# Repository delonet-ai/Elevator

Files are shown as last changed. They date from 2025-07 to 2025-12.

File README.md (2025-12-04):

Project migrateg on ESP32, now available here: https://github.com/delonet-ai/Elevator-ESP32 **WIREELESS REMOTE!!**

Проект переехал на ESP32, доступен вот тут: https://github.com/delonet-ai/Elevator-ESP32

**English version below**
# 🚀 Макет лифта на Arduino
BOM и STL будут внизу.
Фотки в папке pics

Этот проект реализует управление шаговым двигателем с помощью Arduino Nano для перемещения лифта между тремя этажами. Прошивка поддерживает автоматическую калибровку, ручное управление и вызовы на этажи. 
Roadmap:
- Хранение калибровки и текущей позиции в EEPROM
- плавный разгон-торможение
- вывод на дисплей 128х32 точки информации о движении и этаже
- Переделка пульта с 14 жил на 4 через еще одну Arduino Nano
- Перевод на питание через 4S 18650 и BMS
- Экстренный режим (если нажат концевик)
- Перевод в режим рекалибровки и сброс всех данных EEPROM
## ⚙️ Возможности

* Поддержка 3 этажей
* Калибровка верхней и нижней границ
* Режим ручного управления (вверх/вниз)
* Вызов на этажи кнопками
* Световая индикация кнопок
* Отображение статуса в Serial Monitor
* Плавное ускорение и торможение в авто-режиме
* Регулируемая скорость с помощью потенциометра

## 🔌 Подключение компонентов

| Компонент | Пин Arduino | Описание |
| --- | --- | --- |
| Кнопка "Вверх" | D10 | Режим INPUT\_PULLUP |
| Кнопка "Вниз" | D11 | Режим INPUT\_PULLUP |
| Кнопка "Этаж 1" | D7 | Режим INPUT\_PULLUP |
| Кнопка "Этаж 2" | D8 | Режим INPUT\_PULLUP |
| Кнопка "Этаж 3" | D9 | Режим INPUT\_PULLUP |
| Подсветка "Вверх" | D5 | LOW = включено |
| Подсветка "Вниз" | D6 | LOW = включено |
| Подсветка Этаж 1 | D2 | LOW = включено |
| Подсветка Этаж 2 | D3 | LOW = включено |
| Подсветка Этаж 3 | D4 | LOW = включено |
| Шаговый двигатель STEP | D13 | Сигнал шагов |
| Шаговый двигатель DIR  | A3 | Направление вращения |
| Концевик (верхний) | A1 | Режим INPUT\_PULLUP |
| Потенциометр | A2 | Задаёт скорость движения |

Если вы не поняли про водсветку - кнопки у меня с резистром на подсветке, поэтому подключены к +5, а пины дают землю при включении.

## 🛠 Установка
Если вы здесь - вы знаете как загрузить .ino в вашу ардуино

## 📏 Калибровка

1. Кнопками "Вверх" и "Вниз" подведите кабину к верхней точке.
2. Нажмите концевик → верхняя граница будет установлена.
3. Кнопкой "Вниз" опустите кабину до низа.
4. Коротким нажатием кнопки "Этаж 1" установите нижнюю границу.
5. После этого доступен авто-режим: кнопки этажей начинают работать.

## 🚦 Управление

* Нажатие кнопки этажа вызывает лифт к нужному уровню.
* Подсветка кнопки загорается на время движения.
* При движении вверх/вниз вручную используется минимальная скорость.
* В авто-режиме скорость — в зависимости от положения потенциометра (1–15×).

## ⚡ Конфигурация

```cpp
const unsigned int STEP_DELAY = 1000;  // Минимальная задержка (медленное движение)
```

Скорость регулируется через потенциометр на A2 (map в диапазон от 1 до 15).

## 🧪 Отладка

Открывайте Serial Monitor (9600 бод), чтобы видеть:

* Текущую позицию
* Режим работы (MANUAL / AUTO)
* Целевую позицию

---

!!! BOM:
- 4 трубы 25мм - 1 метр (или любая высота)
- 3д принтер и PLA пластик (1-1,5 кг)
- Название	Кол-во	Примечание
- Arduino Nano	https://sl.aliexpress.ru/p?key=4FCD3xc
- Плата для разводки https://sl.aliexpress.ru/p?key=JFCD3Y3
- Шаговый мотор NEMA17
- Плата для драйвера https://sl.aliexpress.ru/p?key=DnCD3wO
- Драйвер A4988	1	Обязательно радиатор и термопрокладка https://sl.aliexpress.ru/p?key=tFCD3EM
- БП 12 В (2–5 А)	или BMS + 4s 16650 + dc-dc на 12В
- Потенциометр 10 кОм	1	
- OLED-дисплей SSD1306 (0.91")	1	I2C, 128×32, SSD1306
- Кнопки с подстветкой https://sl.aliexpress.ru/p?key=mFCD3h2 

!!! STL + Fusion 360 в папке /CAD и по ссылке
https://www.printables.com/model/1353500-elevator-lift-arduino
https://www.thingiverse.com/thing:7089874

Если используете этот проект — ⭐ на GitHub приветствуется!

*Удачных проектов!*

**English version**

🚀 Arduino Elevator Model

BOM and STL are at the bottom.
Photos are in the pics folder.

This project implements a stepper-motor–driven elevator controller based on an Arduino Nano, supporting movement between three floors.
The firmware includes automatic calibration, manual control, and floor call buttons.

Roadmap:

Store calibration and current position in EEPROM

Smooth acceleration/braking

Display movement status and current floor on a 128×32 OLED

Rework the remote controller from 14 wires down to 4 using an additional Arduino Nano

Power the entire system using a 4S 18650 pack and BMS

Emergency mode (triggered by the upper limit switch)

Recalibration mode and EEPROM wipe

⚙️ Features

3-floor support

Calibration of top and bottom limits

Manual control mode (up/down)

Floor-call buttons

Button illumination

Status output via Serial Monitor

Smooth acceleration and braking in auto mode

Adjustable speed via potentiometer

🔌 Component Connections
Component	Arduino Pin	Description
“Up” button	D10	INPUT_PULLUP mode
“Down” button	D11	INPUT_PULLUP mode
Floor 1 button	D7	INPUT_PULLUP mode
Floor 2 button	D8	INPUT_PULLUP mode
Floor 3 button	D9	INPUT_PULLUP mode
Up indicator LED	D5	LOW = on
Down indicator LED	D6	LOW = on
Floor 1 LED	D2	LOW = on
Floor 2 LED	D3	LOW = on
Floor 3 LED	D4	LOW = on
Stepper STEP	D13	Step signal
Stepper DIR	A3	Direction signal
Limit switch (top)	A1	INPUT_PULLUP mode
Potentiometer	A2	Controls movement speed

If you're confused about the LED wiring — the buttons I use have built-in resistors for LEDs.
They are connected to +5V, and Arduino pins provide ground when turning illumination on.

🛠 Installation

If you’re here, you already know how to upload a .ino to your Arduino.

📏 Calibration

Use the “Up” / “Down” buttons to move the cabin to the top position.

Press the limit switch → the upper boundary is saved.

Use the “Down” button to lower the cabin to the bottom.

Short-press the “Floor 1” button to save the bottom boundary.

After this, auto mode becomes available: floor buttons start working.

🚦 Operation

Pressing a floor button moves the elevator to that floor.

The button’s LED lights up during movement.

Manual up/down movement always uses minimum speed.

In auto mode, speed depends on the potentiometer position (1–15×).

⚡ Configuration
const unsigned int STEP_DELAY = 1000;  // Minimum delay (slow movement)

Speed is controlled by the potentiometer on A2 (mapped from 1 to 15).

🧪 Debugging

Open Serial Monitor (9600 baud) to see:

Current position

Mode (MANUAL / AUTO)

Target position

!!! BOM:

25mm pipes ×4 — 1 meter (or any height)

3D printer + PLA filament (1–1.5 kg)

Name | Qty | Notes

Arduino Nano — https://sl.aliexpress.ru/p?key=4FCD3xc

Breakout board — https://sl.aliexpress.ru/p?key=JFCD3Y3

Stepper motor NEMA17

Driver carrier board — https://sl.aliexpress.ru/p?key=DnCD3wO

Driver A4988 ×1 — requires heatsink + thermal pad https://sl.aliexpress.ru/p?key=tFCD3EM

PSU 12 V (2–5 A) or BMS + 4s 16650 + DC-DC to 12 V

Potentiometer 10 kΩ ×1

OLED display SSD1306 (0.91") ×1 — I2C, 128×32, SSD1306

Lighted push buttons — https://sl.aliexpress.ru/p?key=mFCD3h2

!!! STL + Fusion 360 in /CAD and here:
https://www.printables.com/model/1353500-elevator-lift-arduino

https://www.thingiverse.com/thing:7089874

If you use this project — ⭐ on GitHub is appreciated!

Happy building!

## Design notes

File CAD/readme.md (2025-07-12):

Это мой 3д проект, его можно посмотреть вот тут или файлы в этой папке. Тут, скорее всего, они новее.

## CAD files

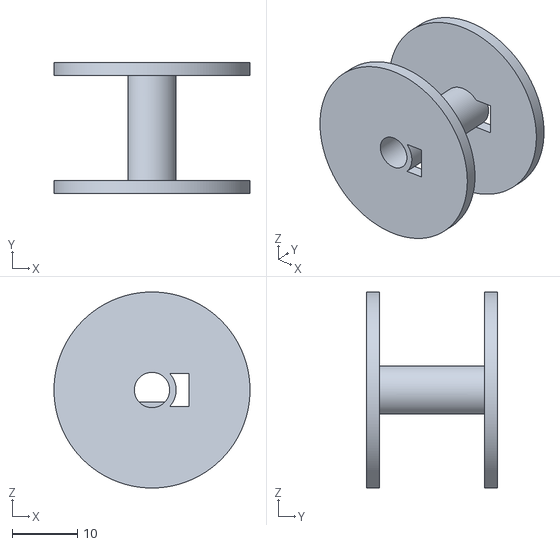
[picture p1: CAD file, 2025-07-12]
CAD/Pulley.stl
30.0 x 20.0 x 30.0

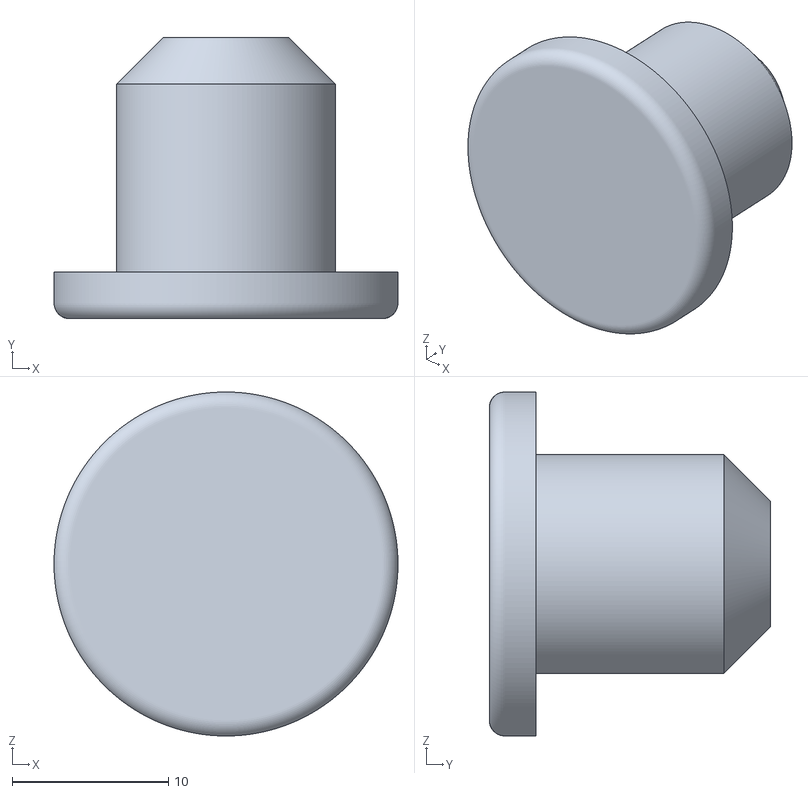
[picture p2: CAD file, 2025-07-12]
CAD/Pin.stl
22.0 x 18.0 x 22.0

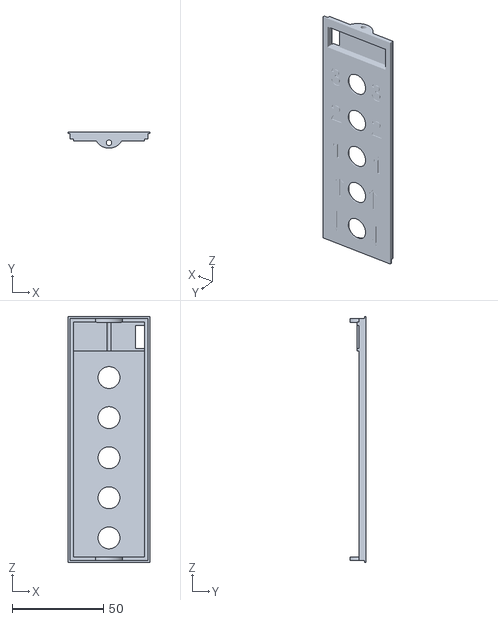
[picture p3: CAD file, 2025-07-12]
CAD/ControlCover.stl
45.0 x 8.99 x 135.0

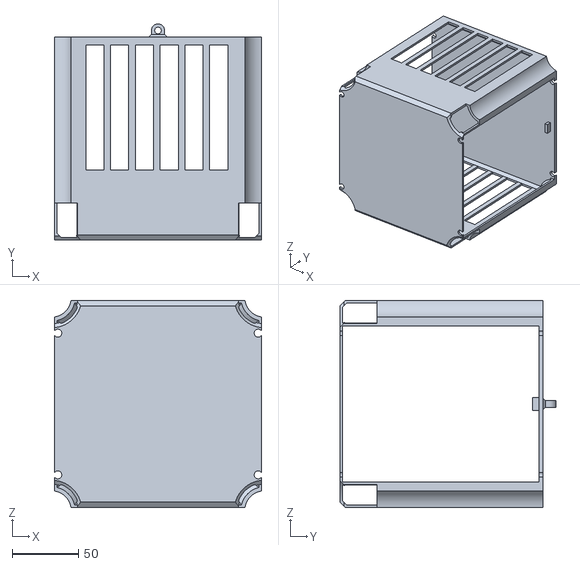
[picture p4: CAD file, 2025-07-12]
CAD/Cabin2.stl
156.0 x 163.0 x 156.0

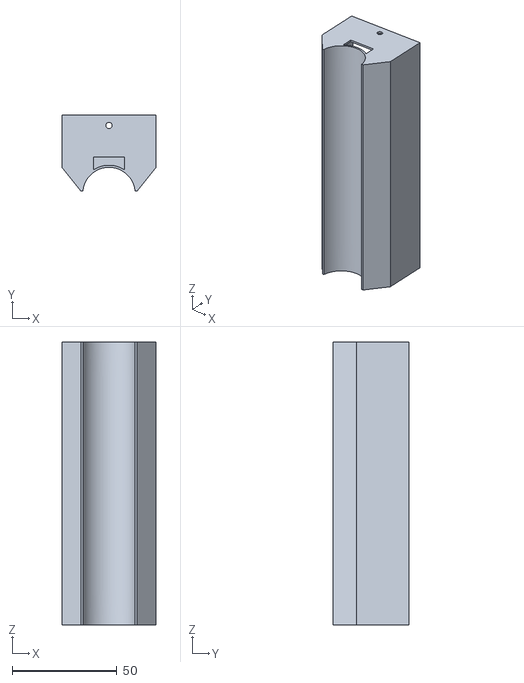
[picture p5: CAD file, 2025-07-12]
CAD/ControlBox.stl
45.0 x 36.3 x 135.0

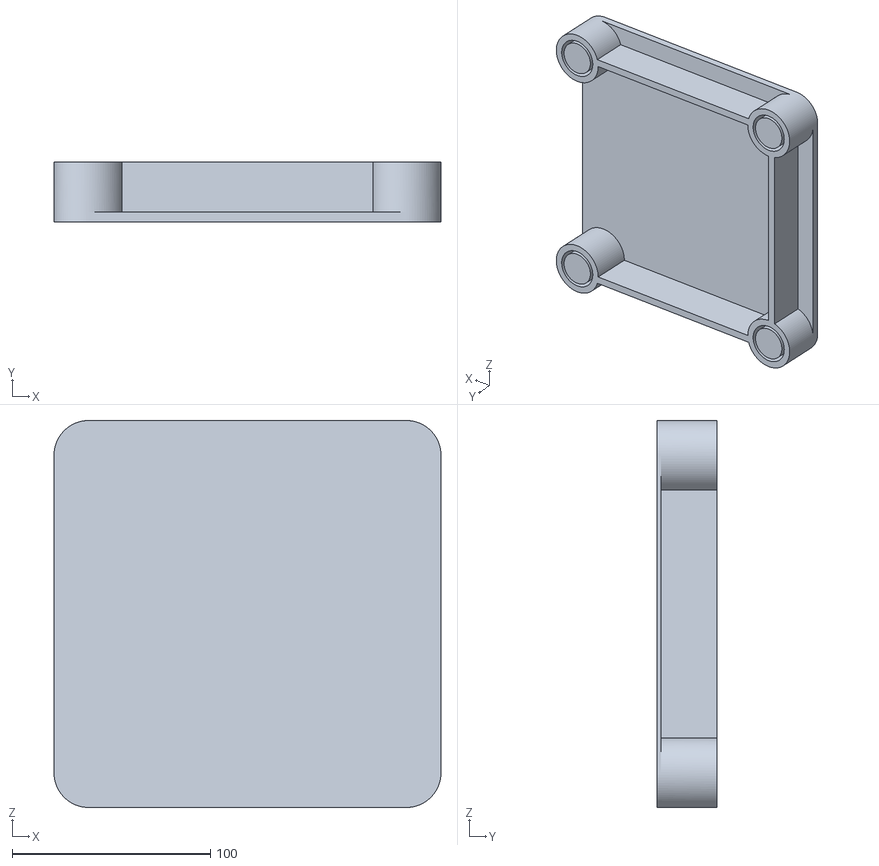
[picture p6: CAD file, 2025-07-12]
CAD/Bottom.stl
195.0 x 30.0 x 195.0

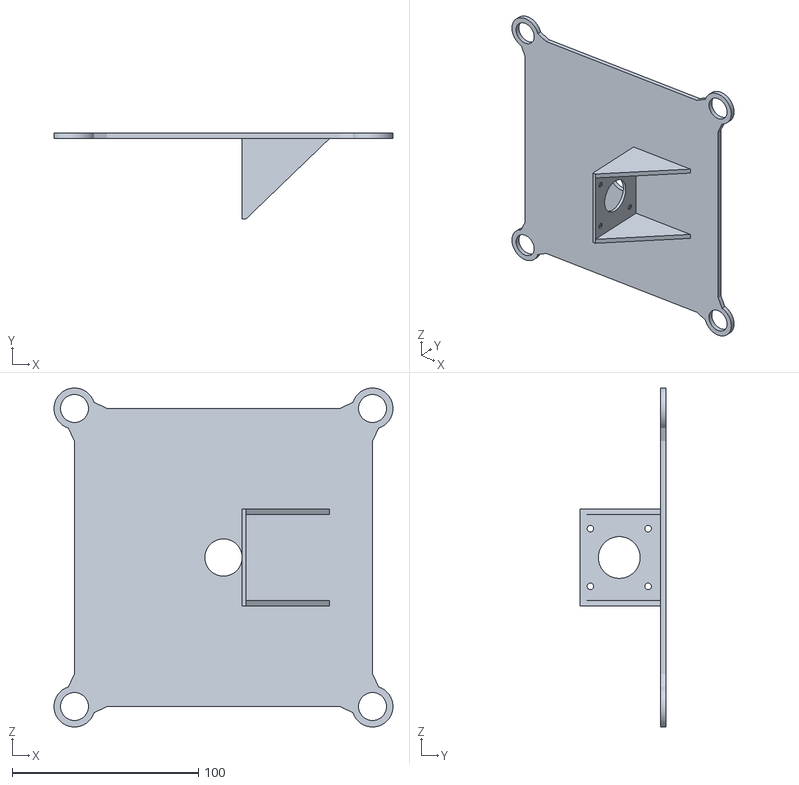
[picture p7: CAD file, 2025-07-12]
CAD/DriveBoard.stl
182.0 x 46.3 x 182.0

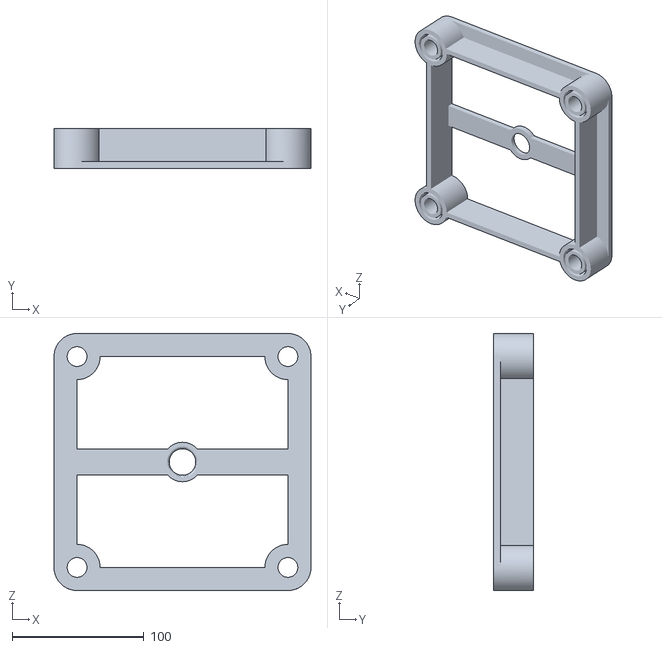
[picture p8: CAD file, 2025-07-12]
CAD/Top.stl
195.0 x 30.0 x 195.0

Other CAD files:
CAD/Elevator v19.f3d

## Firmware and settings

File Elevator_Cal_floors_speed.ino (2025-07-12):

// Elevator Sketch with Floor Call Logic
// Calibration (upper and lower limits) then floor calls for 3 floors

#include <Arduino.h>

// Pin Definitions
#define BTN_UP        10    // Manual UP (INPUT_PULLUP)
#define BTN_DOWN      11    // Manual DOWN
#define BTN_FLOOR1    7     // Floor1: first sets lower limit, then floor call
#define BTN_FLOOR2    8     // Floor2 call
#define BTN_FLOOR3    9     // Floor3 call
#define PIN_STEP      13    // Stepper STEP pin
#define PIN_DIR       A3    // Stepper DIR pin
#define LIMIT_TOP     A1    // Top limit switch (INPUT_PULLUP)
#define PIN_POT       A2    // Potentiometer for speed factor (analog input)

// LED Pins (active-low: LOW = ON)
#define LED_UP        5
#define LED_DOWN      6
#define LED_FLOOR1    2
#define LED_FLOOR2    3
#define LED_FLOOR3    4

// Timing constants
const unsigned int STEP_DELAY       = 100;  // base delay in microseconds
const unsigned long BLINK_INTERVAL  = 200;   // ms for floor LEDs fast blink

// State tracking
long positionCounter    = 0;
bool upperLimitLocked   = false;
bool lowerLimitSet      = false;
long lowerLimit         = 0;       // threshold for DOWN movement
long floor3Limit        = 0;       // 2% from lowerLimit

// Floor call logic
enum MoveMode { MANUAL, AUTO };
MoveMode mode = MANUAL;
long targetPosition = -1;

// Edge tracking
bool lastFloor1State    = HIGH;
bool lastFloor2State    = HIGH;
bool lastFloor3State    = HIGH;
bool lastLimitState     = HIGH;

// LED blink for floor buttons
unsigned long blinkLastTime = 0;
bool blinkState            = false;

// Speed factor variable
unsigned int stepDelay = STEP_DELAY;

void setup() {
  Serial.begin(9600);
  while (!Serial);
  Serial.println("[Setup] Elevator ready");

  // Configure inputs
  pinMode(BTN_UP, INPUT_PULLUP);
  pinMode(BTN_DOWN, INPUT_PULLUP);
  pinMode(BTN_FLOOR1, INPUT_PULLUP);
  pinMode(BTN_FLOOR2, INPUT_PULLUP);
  pinMode(BTN_FLOOR3, INPUT_PULLUP);
  pinMode(LIMIT_TOP, INPUT_PULLUP);
  pinMode(PIN_POT, INPUT);

  // Configure motor outputs
  pinMode(PIN_STEP, OUTPUT);
  pinMode(PIN_DIR, OUTPUT);

  // Configure LEDs
  pinMode(LED_UP, OUTPUT); digitalWrite(LED_UP, HIGH);
  pinMode(LED_DOWN, OUTPUT); digitalWrite(LED_DOWN, HIGH);
  pinMode(LED_FLOOR1, OUTPUT); digitalWrite(LED_FLOOR1, HIGH);
  pinMode(LED_FLOOR2, OUTPUT); digitalWrite(LED_FLOOR2, HIGH);
  pinMode(LED_FLOOR3, OUTPUT); digitalWrite(LED_FLOOR3, HIGH);
}

void loop() {
  unsigned long now = millis();

  // Read speed factor from potentiometer
  int potVal = analogRead(PIN_POT);             // 0..1023
  unsigned int factor = map(potVal, 0, 1023, 1, 15);
  stepDelay = STEP_DELAY * factor;

  // Read inputs
  bool upHeld     = (digitalRead(BTN_UP) == LOW);
  bool downHeld   = (digitalRead(BTN_DOWN) == LOW);
  bool f1         = (digitalRead(BTN_FLOOR1) == LOW);
  bool f2         = (digitalRead(BTN_FLOOR2) == LOW);
  bool f3         = (digitalRead(BTN_FLOOR3) == LOW);
  bool limitTop   = (digitalRead(LIMIT_TOP) == LOW);

  // Handle top limit (edge)
  if (limitTop && lastLimitState == HIGH) {
    positionCounter = 0;
    upperLimitLocked = true;
    Serial.println("[Calib] Top set, Counter=0");
  }
  lastLimitState = limitTop;

  // Lower limit setup: only if upper calibrated but lower not set
  if (upperLimitLocked && !lowerLimitSet && f1 && lastFloor1State == HIGH) {
    lowerLimitSet = true;
    lowerLimit = positionCounter;
    floor3Limit = (long)(lowerLimit * 0.02);  // compute third floor offset
    Serial.print("[Calib] Lower set="); Serial.println(lowerLimit);
    Serial.print("[Calib] Floor3 limit="); Serial.println(floor3Limit);
  }

  // Floor calls: only after both limits set, f1 now acts as call
  if (upperLimitLocked && lowerLimitSet && mode == MANUAL) {
    if (f1 && lastFloor1State == HIGH) {
      targetPosition = lowerLimit;
      mode = AUTO;
      Serial.print("[Call] Floor1 target="); Serial.println(targetPosition);
    } else if (f2 && lastFloor2State == HIGH) {
      targetPosition = lowerLimit / 2;
      mode = AUTO;
      Serial.print("[Call] Floor2 target="); Serial.println(targetPosition);
    } else if (f3 && lastFloor3State == HIGH) {
      targetPosition = (long)(lowerLimit * 0.02);
      mode = AUTO;
      Serial.print("[Call] Floor3 target="); Serial.println(targetPosition);
    }
  }
  lastFloor1State = f1;
  lastFloor2State = f2;
  lastFloor3State = f3;

  // Update blink state for floor LEDs
  if (now - blinkLastTime >= BLINK_INTERVAL) {
    blinkLastTime = now;
    blinkState = !blinkState;
  }

  // Floor LED logic
  if (!upperLimitLocked) {
    // Before top limit set: blink floors 1-3
    digitalWrite(LED_FLOOR1, blinkState ? LOW : HIGH);
    digitalWrite(LED_FLOOR2, blinkState ? LOW : HIGH);
    digitalWrite(LED_FLOOR3, blinkState ? LOW : HIGH);
  } else if (upperLimitLocked && !lowerLimitSet) {
    // After top limit only: Floor1 steady on
    digitalWrite(LED_FLOOR1, LOW);
    digitalWrite(LED_FLOOR2, HIGH);
    digitalWrite(LED_FLOOR3, HIGH);
  } else {
    // After both limits: default floors off
    digitalWrite(LED_FLOOR1, HIGH);
    digitalWrite(LED_FLOOR2, HIGH);
    digitalWrite(LED_FLOOR3, HIGH);
  }

  // Floor call indication during AUTO mode
  if (mode == AUTO) {
    // Light target floor LED until arrival
    if (targetPosition == lowerLimit) {
      digitalWrite(LED_FLOOR1, LOW);
    } else if (targetPosition == lowerLimit/2) {
      digitalWrite(LED_FLOOR2, LOW);
    } else if (targetPosition == (long)(lowerLimit*0.02)) {
      digitalWrite(LED_FLOOR3, LOW);
    }
  }

  // UP/DOWN LED logic: on when movement allowed (manual or auto)
  bool canUp;
  if (mode == MANUAL && lowerLimitSet) canUp = (positionCounter > floor3Limit);
  else canUp = (!upperLimitLocked || positionCounter > 0);
  bool canDown = (!lowerLimitSet || positionCounter < lowerLimit);
  digitalWrite(LED_UP,   canUp ? LOW : HIGH);
  digitalWrite(LED_DOWN, canDown ? LOW : HIGH);

  // Movement logic
  if (mode == MANUAL) {
    // Manual UP limited by floor3Limit after calibration
    if (upHeld && ((lowerLimitSet && positionCounter > floor3Limit) || (!lowerLimitSet && (!upperLimitLocked || positionCounter > 0)))) stepMove(1);
    if (downHeld && (!lowerLimitSet || positionCounter < lowerLimit)) stepMove(-1);
  } else {
    if (positionCounter < targetPosition) stepMove(-1);
    else if (positionCounter > targetPosition) stepMove(1);
    else { Serial.println("[Arrive] Target reached"); mode = MANUAL; }
  }
}

// stepMove: dir +1 up, -1 down
void stepMove(int dir) {
  digitalWrite(PIN_DIR, dir>0?HIGH:LOW);
  digitalWrite(PIN_STEP, HIGH);
  delayMicroseconds(stepDelay);
  digitalWrite(PIN_STEP, LOW);
  delayMicroseconds(stepDelay);
  positionCounter += (dir<0?1:-1);
}

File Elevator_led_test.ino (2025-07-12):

// Continuous Motor Control with Counter, Limit Switch, and LED Indication

#include <Arduino.h>

// Pin Definitions
#define BTN_UP        10    // UP button (INPUT_PULLUP)
#define BTN_DOWN      11    // DOWN button (INPUT_PULLUP)
#define BTN_FLOOR1    7     // Floor1 limit set button (INPUT_PULLUP)
#define PIN_STEP      13    // Stepper STEP pin
#define PIN_DIR       A3    // Stepper DIR pin
#define LIMIT_TOP     A1    // Top limit switch (INPUT_PULLUP)

// LED Pins (active-low: LOW = ON)
#define LED_UP        5     // UP LED
#define LED_DOWN      6     // DOWN LED
#define LED_FLOOR1    2     // Floor1 LED (blink fast)
#define LED_FLOOR2    3     // Floor2 LED
#define LED_FLOOR3    4     // Floor3 LED

// Timing constants
const unsigned int STEP_DELAY       = 1000;  // us between motor steps
const unsigned long BLINK_INTERVAL  = 200;   // ms for floor LEDs fast blink

// State tracking
long positionCounter    = 0;
bool upperLimitLocked   = false;   // locks UP after top limit
bool lowerLimitSet      = false;
long lowerLimit         = 0;       // threshold for DOWN movement

// Edge tracking
bool lastFloor1State    = HIGH;
bool lastLimitState     = HIGH;

// LED blink state for floor LEDs
unsigned long blinkLastTime = 0;
bool blinkState            = false;

void setup() {
  Serial.begin(9600);
  while (!Serial);
  Serial.println("[Setup] Motor + LEDs ready");

  // Configure inputs
  pinMode(BTN_UP, INPUT_PULLUP);
  pinMode(BTN_DOWN, INPUT_PULLUP);
  pinMode(BTN_FLOOR1, INPUT_PULLUP);
  pinMode(LIMIT_TOP, INPUT_PULLUP);

  // Configure motor outputs
  pinMode(PIN_STEP, OUTPUT);
  pinMode(PIN_DIR, OUTPUT);

  // Configure LED outputs (active-low)
  pinMode(LED_UP, OUTPUT);
  pinMode(LED_DOWN, OUTPUT);
  pinMode(LED_FLOOR1, OUTPUT);
  pinMode(LED_FLOOR2, OUTPUT);
  pinMode(LED_FLOOR3, OUTPUT);

  // Turn off LEDs initially
  digitalWrite(LED_UP, HIGH);
  digitalWrite(LED_DOWN, HIGH);
  digitalWrite(LED_FLOOR1, HIGH);
  digitalWrite(LED_FLOOR2, HIGH);
  digitalWrite(LED_FLOOR3, HIGH);
}

void loop() {
  unsigned long now = millis();

  // Read inputs
  bool upHeld     = (digitalRead(BTN_UP) == LOW);
  bool downHeld   = (digitalRead(BTN_DOWN) == LOW);
  bool floor1     = (digitalRead(BTN_FLOOR1) == LOW);
  bool topSwitch  = (digitalRead(LIMIT_TOP) == LOW);

  // Handle top limit (edge)
  if (topSwitch && lastLimitState == HIGH) {
    Serial.println("[Limit] Top switch activated");
    positionCounter = 0;
    upperLimitLocked = true;
    Serial.println("[Counter]=0, UP locked");
  }
  lastLimitState = topSwitch;

  // Handle lower limit set by Floor1 (edge)
  if (floor1 && lastFloor1State == HIGH) {
    lowerLimitSet = true;
    lowerLimit = positionCounter;
    Serial.print("[LimitLow] set="); Serial.println(lowerLimit);
  }
  lastFloor1State = floor1;

  // Update blink state for floor LEDs
  if (now - blinkLastTime >= BLINK_INTERVAL) {
    blinkLastTime = now;
    blinkState = !blinkState;
  }

  // Floor LED logic: blink fast until upper limit set
  if (!upperLimitLocked) {
    digitalWrite(LED_FLOOR1, blinkState ? LOW : HIGH);
    digitalWrite(LED_FLOOR2, blinkState ? LOW : HIGH);
    digitalWrite(LED_FLOOR3, blinkState ? LOW : HIGH);
  } else {
    // After upper limit: Floor1 on until lower limit set, others off
    digitalWrite(LED_FLOOR1, lowerLimitSet ? HIGH : LOW);
    digitalWrite(LED_FLOOR2, HIGH);
    digitalWrite(LED_FLOOR3, HIGH);
  }

  // UP/DOWN LED logic: glow when active (available to move)
  // UP active if UP command allowed
  if (!upperLimitLocked || positionCounter > 0) {
    digitalWrite(LED_UP, LOW);
  } else {
    digitalWrite(LED_UP, HIGH);
  }

  // DOWN active if DOWN command allowed
  if (!lowerLimitSet || positionCounter < lowerLimit) {
    digitalWrite(LED_DOWN, LOW);
  } else {
    digitalWrite(LED_DOWN, HIGH);
  }

  // Motor control
  if (upHeld && (!upperLimitLocked || positionCounter > 0)) {
    digitalWrite(PIN_DIR, HIGH);
    stepOnce(); positionCounter--; }
  if (downHeld && (!lowerLimitSet || positionCounter < lowerLimit)) {
    digitalWrite(PIN_DIR, LOW);
    stepOnce(); positionCounter++; }
}

void stepOnce() {
  digitalWrite(PIN_STEP, HIGH);
  delayMicroseconds(STEP_DELAY);
  digitalWrite(PIN_STEP, LOW);
  delayMicroseconds(STEP_DELAY);
}
